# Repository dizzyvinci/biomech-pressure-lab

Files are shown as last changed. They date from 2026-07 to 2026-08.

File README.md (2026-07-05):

# Personal Biomechanics Lab

Measure how your foot is loaded — all day — and turn that into a **custom 3D-printed insole**
plus a plain-language read on **which tissues the load is stressing**. A ~$100 wearable and a
printer doing what a $5k+ gait lab does, at home.

> **Part of the biomech-lab family — the hardware / pressure side.** Its sibling **`biomech-lab`**
> covers markerless *motion* (webcam→OpenSim, DICOM/MRI bone geometry). **This** repo is the
> **build-your-own** side: a printed insole, an optional smart-insole sensor rig, and a DIY force
> plate + pressure mat you fabricate yourself.
>
> 🎤 One-pager pitch: [**PITCH.md**](PITCH.md) · 🩺 *A design & screening aid, not a medical device.*

---

## The flow — one loop, end to end

The whole system, end to end

Everything in the repo is a stage of one loop:

| # | Stage | Does | Tool |
|---|---|---|---|
| 1 | **Capture** | log foot pressure (8× FSR) + motion, all day | [`firmware/all_day_logger`](firmware/all_day_logger/all_day_logger.ino) |
| 2 | **Calibrate** | turn raw ADC into real **kPa** | [`calibrate.py`](analysis/calibrate.py) |
| 3 | **Analyze** | hot spot, pronation, cadence, balance/sway | [`interpret.py`](analysis/interpret.py) · [`balance.py`](analysis/balance.py) |
| 4 | **Dose** | the all-day **CPTS** load → which **nerves & fascia** it stresses | [`day_summary.py`](analysis/day_summary.py) → [`nerve_fascia.py`](analysis/nerve_fascia.py) |
| 5 | **Design** | a relief window + met pad + arch that follow the findings | [`build_insole.py`](hardware/build_insole.py) |
| 6 | **Print** | soft cushion + firm shell in one part | your **multi-material printer** |
| ↻ | **Track** | wear it, re-measure, watch the dose fall week over week | [`trend.py`](analysis/trend.py) |

**Two ways in, one destination:** Path 1 designs the insole *by feel* (no electronics); Path 2 adds
the sensor rig for *objective data*. **No hardware at all?** Every tool runs on the committed
sample with `--demo`.

---

## What you need to build it

### 🖨️ To PRINT the insole — a multi-material 3D printer  *(the one physical must-have)*
The insole is a **soft cushion + firm shell in a single print**, so it needs a printer that runs
two materials (e.g. a **Bambu Lab H2D** with the TPU High-Flow kit). This is the piece the whole
Path-1 workflow depends on.

| Part | Why |
|---|---|
| **Bambu Lab H2D** (or any multi-material printer) | prints soft cushion + firm shell in one insole |
| **TPU High-Flow kit** | nozzles tuned for flexible TPU |
| **Soft / foaming TPU** (e.g. VarioShore) | the squishy heel cushion that won't bottom out |
| **Firm TPU 95A** | the support shell |
| **PLA / PETG** | optional — enclosures, the DIY-lab frames, the FSR pucks |

Full list + links: [docs/parts_list.md](docs/parts_list.md).

### 🔬 To MEASURE (optional) — the sensor rig or the DIY lab
- **Smart-insole rig** (~$70–120): ESP32-S3 + 8× FSR + mux + IMU + microSD + LiPo. Gives a real
  hot-spot map and before/after proof. → **Path 2** below.
- **DIY lab instruments** (~$150): a **load-cell force plate** (vertical GRF ×BW) and a **Velostat
  pressure mat** (full-foot map) you print + wire. → [docs/build_lab.md](docs/build_lab.md).

---

## ▶️ Try it now — no hardware needed
[`sample/`](sample/README.md) runs the **entire pipeline on a synthetic day** (~5 s, every output
committed): calibrate → real kPa → hot spot → **an insole the software designs itself** → the
all-day dose → nerve/fascia read → a balance screen.

<p align="center">
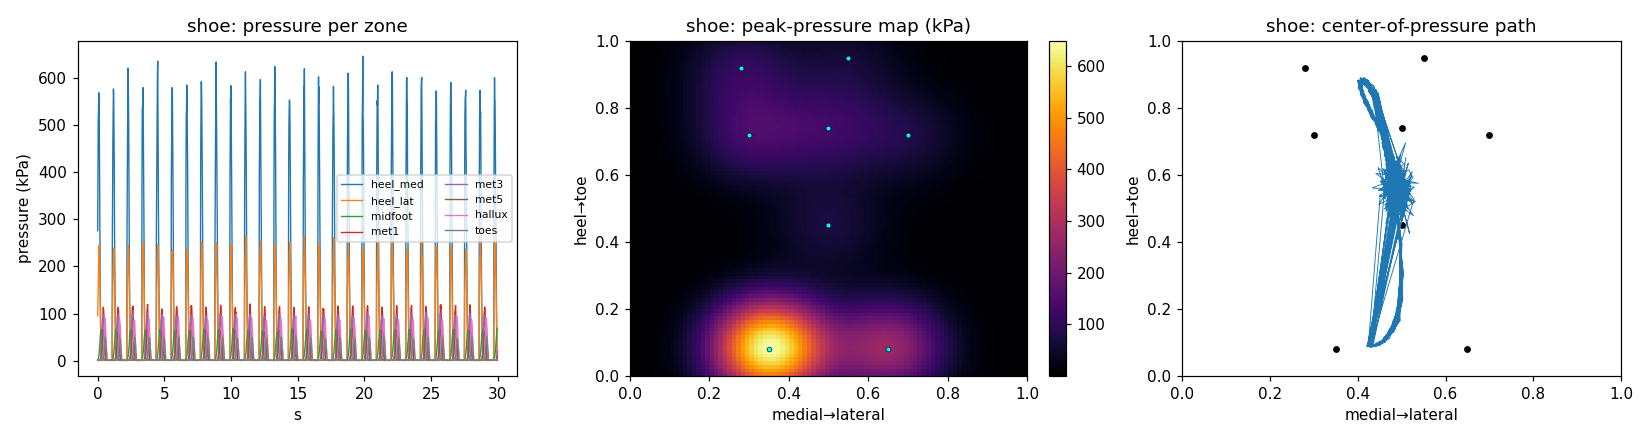
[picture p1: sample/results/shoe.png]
worked example: pressure per zone, peak-pressure heatmap, center-of-pressure path
  
</p>

**Worked result:** hot spot **heel_med (645 kPa, 40% of load)**, medial pronation, heel-dominant; the
shoe *adds* +13 pts vs barefoot → an **aggressive medial-heel relief insole with arch support**
([`hardware/relief_insole.stl`](hardware/relief_insole.stl)); the all-day dose flags **plantar fascia /
Baxter's / tibial** (tell-apart by time-of-day); balance **Romberg 3.6** (vision-reliant).

```bash
cd analysis
python make_sample_data.py --out ../sample                                      # fake a day
python calibrate.py ../sample/cal_points.csv --out ../sample/calibration.json --r-fixed 1000
python interpret.py "../sample/sample_day_*.csv" --calibration ../sample/calibration.json --out ../sample/results
python nerve_fascia.py --logs "../sample/sample_day_*.csv" ../sample/sample_seated_bounce.csv \
    --calibration ../sample/calibration.json --walk-hours 10 --bounce-hours 4 --out ../sample/results
cd ../hardware && python build_insole.py --spec ../sample/results/insole_spec.json --out .
```
Full walkthrough: [sample/README.md](sample/README.md) · both paths step-by-step: [docs/quickstart.md](docs/quickstart.md).

---

## 🖨️ Path 1 — printer-first (start here)
No electronics, no soldering. You already know where it hurts.
1. **Scan** your orthotic → STL (iPhone photogrammetry: Scaniverse/Polycam) — [docs/insole_print_spec.md](docs/insole_print_spec.md) §1.
2. **Mark** the sore spot on the scan.
3. **Design** the insole (soft heel cushion + firm shell + a **relief pocket** there) — or let
   [`build_insole.py`](hardware/build_insole.py) generate it, **fitted to your foot** ([how](docs/fit_to_your_foot.md)).
4. **Print** in TPU on the H2D (soft + firm in one part).
5. **Wear it**, nudge the window/density by feel, **reprint.** That's the loop — no measurement hardware.

---

## 🔬 Path 2 — the sensor rig (optional, advanced)
Add this only when you want to *measure* the hot spot instead of placing it by feel. The full
all-day, **barefoot-and-shoe** build is spec'd end-to-end in
[**docs/path2_tracking_build.md**](docs/path2_tracking_build.md) — electronics ride in an **ankle
pod** ([`hardware/ankle_pod.scad`](hardware/ankle_pod.scad)), not underfoot.

How the smart-insole rig fits together

<details>
<summary><b>Sensor-rig BOM, wiring, FSR map & data format</b></summary>

**BOM (~$70–120):** ESP32-S3 DevKitC-1 · 8× **FSR402** · **CD74HC4067** 16-ch mux · **BNO085** IMU ·
microSD SPI module · 8× 10 kΩ · LiPo 500 mAh + **TP4056** · EVA/wire/tape.
*(DIY FSR insoles validate to **r ≈ 0.87** vs pro systems — plenty for relative hot-spot mapping.)*
Each part explained: [docs/what-each-part-is-for.md](docs/what-each-part-is-for.md).

**Wiring (ESP32-S3):** mux SIG→GPIO1 (ADC1_CH0); mux S0–S3→GPIO2/3/4/5; IMU SDA/SCL→GPIO8/9;
SD CS/MOSI/SCK/MISO→GPIO10/11/12/13; button→GPIO14; LED→GPIO15. Each FSR:
`3V3 ── FSR ──●── 10kΩ ── GND`, node `●` → a mux channel.

**FSR → foot-zone map** (channel order in firmware/analysis):
```
        toes                  0 heel_med   4 met3
   hallux   met5              1 heel_lat   5 met5
 met1   met3                  2 midfoot    6 hallux
      midfoot                 3 met1       7 toes
 heel_med  heel_lat
```

**Data (CSV, ~50–100 Hz):** `t_ms,mode,phase,fsr0..fsr7,qw,qx,qy,qz,ax,ay,az,vbat`
(`phase` = walk/stand/bounce/other; short-press cycles it so a day segments for the dose model).
</details>

---

## 🧰 The toolbox — `analysis/`, by job
Every script runs standalone with `--demo`. Grouped by what you're asking:

| Job | Scripts |
|---|---|
| **Calibration & data** | [`calibrate.py`](analysis/calibrate.py) (fit ADC→kPa) · [`calib.py`](analysis/calib.py) (shared model) · [`make_sample_data.py`](analysis/make_sample_data.py) |
| **Pressure & insole** | [`interpret.py`](analysis/interpret.py) (findings + insole directives) · [`analyze_pressure.py`](analysis/analyze_pressure.py) (peak/impulse/CoP plots) · [`zone_load.py`](analysis/zone_load.py) (per-met vs cited norms) |
| **Balance & sway** | [`balance.py`](analysis/balance.py) (sway, Romberg) · [`balance_positions.py`](analysis/balance_positions.py) (mCTSIB, single-leg, LOS) · [`beam_balance.py`](analysis/beam_balance.py) (athlete/beam) · [`landing_lab.py`](analysis/landing_lab.py) |
| **All-day dose → tissue** | [`bounce.py`](analysis/bounce.py) (the at-rest forefoot dose) · [`day_summary.py`](analysis/day_summary.py) (day → peak/PTI/cycles) · [`nerve_fascia.py`](analysis/nerve_fascia.py) (CPTS → structures) · [`trend.py`](analysis/trend.py) (dose over weeks) |
| **DIY-lab instruments** | [`mat_heatmap.py`](analysis/mat_heatmap.py) (Velostat map) · firmware: [`force_plate`](firmware/force_plate/force_plate.ino) · [`pressure_mat`](firmware/pressure_mat/pressure_mat.ino) |
| **Integrations** | [`integrations/`](integrations/README.md): `video_force` · `apple_watch` · `gait_cue` · `walker` · `api_server` |

---

## 🗺️ Repository map
| Folder | What's in it |
|---|---|
| [`analysis/`](analysis/) | all the Python — the toolbox above |
| [`firmware/`](firmware/) | ESP32 sketches: `all_day_logger`, `smart_insole`, `fsr_calibrate`, `force_plate`, `pressure_mat` |
| [`hardware/`](hardware/README.md) | printable models (`.scad`+`.stl`): insole, ankle pod, sole, force plate, mat, FSR puck + [`build_insole.py`](hardware/build_insole.py) |
| [`refs/`](refs/README.md) | `plantar_norms.json` — the **cited** norms DB (pressures, thresholds, conditions, nerve/fascia structures) |
| [`sample/`](sample/README.md) | the reproducible worked example + committed outputs |
| [`docs/`](docs/README.md) | guides, specs, and the diagram source — **[docs index →](docs/README.md)** |
| [`integrations/`](integrations/README.md) | Apple Watch / cueing glasses / walker / REST API |

---

## 🖼️ Gallery
The system in pictures, grouped. (Diagrams are code-generated — [`docs/make_graphics.py`](docs/make_graphics.py).)

<details open>
<summary><b>Foundations & flow</b></summary>

System pipeline
Physical setup — electronics off the foot
Ordered vs printed BOM
A day of use
</details>

<details>
<summary><b>Pressure, insole & conditions</b></summary>

Plantar pressure atlas — real published kPa
Zone load vs the field
Condition-aware (toe-walking, equinus, heel pain)
Heel lifts & pressure-time integral
Kinetic chain + video→force
</details>

<details>
<summary><b>Balance & sport</b></summary>

Software modules — pressure + balance
Balance module detail — Romberg, fall risk
Balance across positions — mCTSIB, single-leg, LOS
Balance-assist ecosystem — Apple Watch, cueing glasses, walkers
Beam / athlete balance — the landing "stick"
Landing lab — one landing, three rubrics
</details>

<details>
<summary><b>The all-day dose → nerves & fascia</b></summary>

The hidden forefoot dose — leg-bounce
Nerve & fascia impact — CPTS → structures
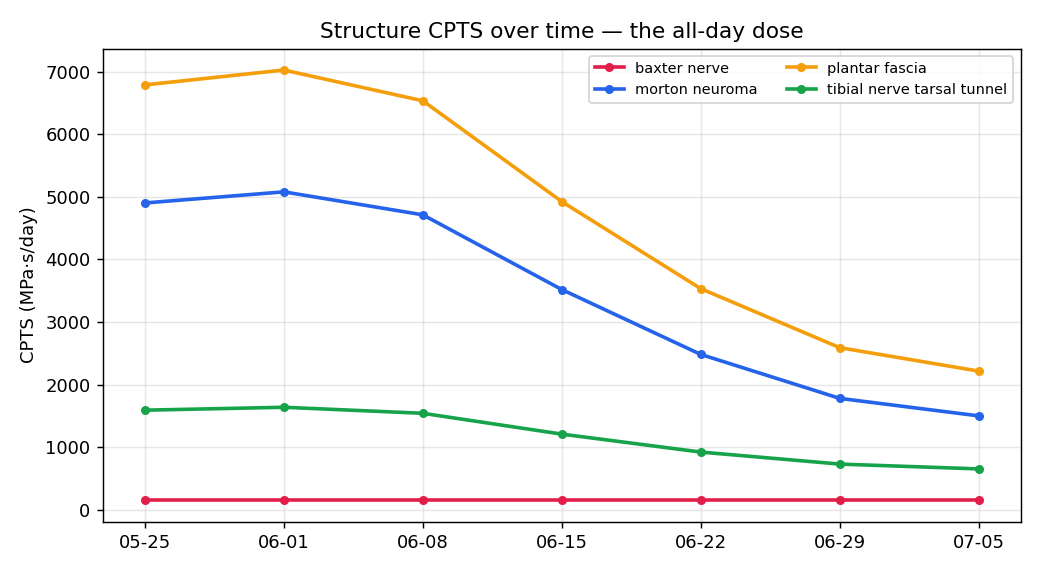
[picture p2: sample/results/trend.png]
CPTS trend over time

</details>

<details>
<summary><b>Build the DIY lab</b></summary>

Personal-lab scope — vs the papers' $10-30k gear
Maker hacks — reclaim the accuracy cheap sensors lose
</details>

---

## ⚠️ Safety & expectations
A **design & screening aid, not a medical device** — pair it with a clinician for pain. FSRs give
**relative, repeatable** pressure (calibrate for kPa; they drift — read trends). The nerve/fascia
read is **screening, not diagnosis** — those structures overlap, and confirming one needs an exam
+ imaging or a diagnostic block. You already have custom orthotics; treat this as tuning on top.

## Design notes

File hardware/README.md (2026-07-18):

# hardware — the printable 3D models

Parametric **OpenSCAD** source **plus pre-rendered STLs** — ready to slice today.

| Source | STL (ready to slice) | Preview | Print in | What |
|---|---|---|---|---|
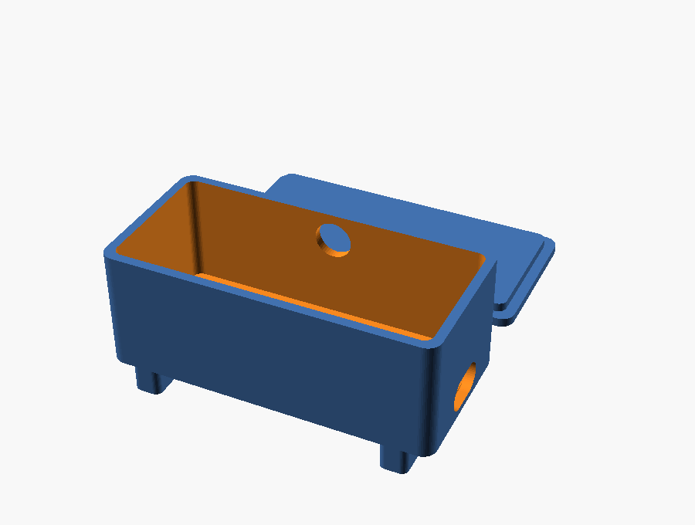
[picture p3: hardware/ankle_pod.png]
ankle pod
| [`ankle_pod.scad`](ankle_pod.scad) | [`ankle_pod.stl`](ankle_pod.stl) |  | PLA / PETG | Enclosure for ESP32-S3 + LiPo + microSD; USB-C + button + ribbon cutouts + strap slots |
| [`ankle_pod_enclosure.scad`](ankle_pod_enclosure.scad) | *(no STL yet — customize + export)* | — | PETG / PLA-CF | **STEMMA-QT revision** of the ankle pod — ESP32-C6 Feather + LiPo 2500 mAh + MPU-6050, snap lid. See [`../docs/BUILD_PLAN.md`](../docs/BUILD_PLAN.md) |
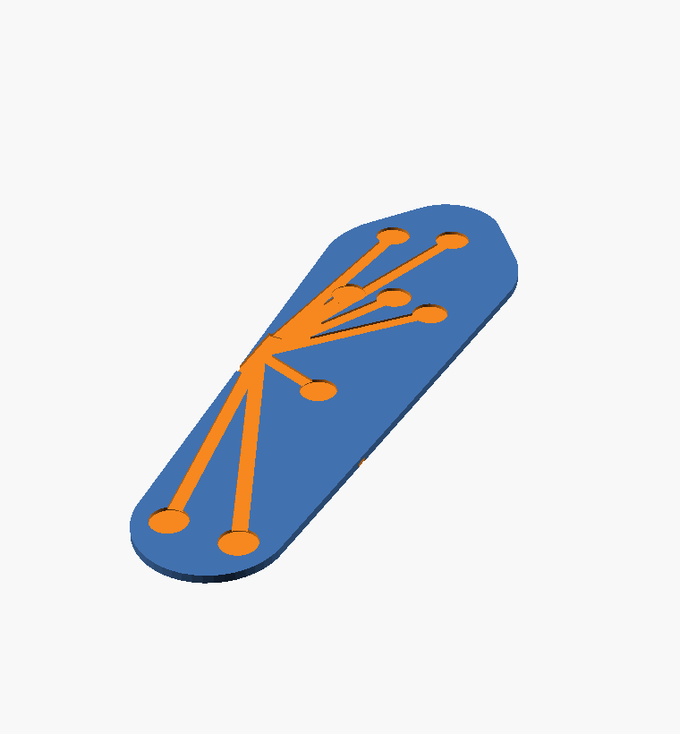
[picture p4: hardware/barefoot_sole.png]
barefoot sole
| [`barefoot_sole.scad`](barefoot_sole.scad) | [`barefoot_sole.stl`](barefoot_sole.stl) |  | **soft TPU 85A** | Thin footbed with 8 FSR pockets + wire channels + strap slots |
| [`insole_fsr_layout.scad`](insole_fsr_layout.scad) | *(no STL yet — customize + export)* | — | soft TPU (or PLA for a quick jig) | **6-zone FSR carrier/layout plate** for the STEMMA-QT rig — parametric off one `FOOT_LEN`. See [`../docs/insole_sensor_layout.md`](../docs/insole_sensor_layout.md) |
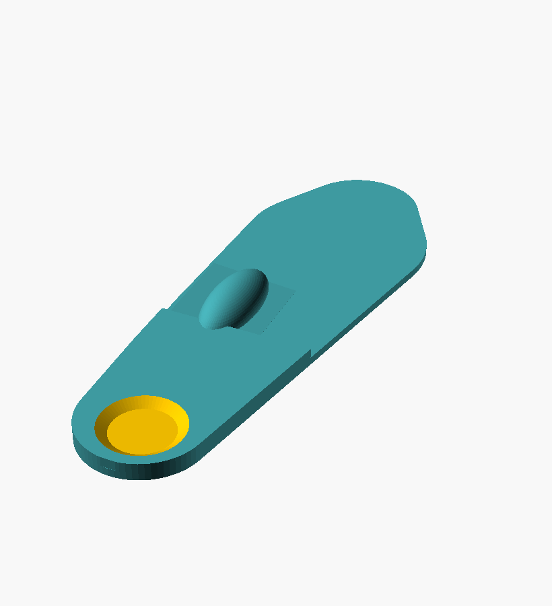
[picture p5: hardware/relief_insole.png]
insole
| [`build_insole.py`](build_insole.py) | [`relief_insole.stl`](relief_insole.stl) |  | soft + firm TPU | **The relief insole** — generated from `insole_spec.json`; fits to your foot (see below) |

## 🦶 Fit the relief insole to your foot
`build_insole.py` reads your analysis (`insole_spec.json`) and emits the insole with the
relief window / posting / cushion placed **from your data**. Three fit levels:
```bash
# generic footbed
python build_insole.py --spec ../sample/results/insole_spec.json
# fitted to your measurements (mm)
python build_insole.py --spec ... --length 262 --forefoot-width 99 --heel-width 64 --arch-height 14
# fitted to a scan of your existing orthotic (best)
python build_insole.py --spec ... --scan my_orthotic.stl --name fitted
```
Full how-to (measuring, scanning, mesh cleanup): [`../docs/fit_to_your_foot.md`](../docs/fit_to_your_foot.md).

## 🔬 Bigger builds — the DIY lab (close the equipment gaps)
Printable instruments that add what the insole can't — see [`../docs/build_lab.md`](../docs/build_lab.md)
and the scope in [`../docs/lab_scope.md`](../docs/lab_scope.md).

| File | STL | Print | What it builds |
|---|---|---|---|
| [`force_plate.scad`](force_plate.scad) | [`force_plate.stl`](force_plate.stl) | PETG, 100% infill | **Force plate** — 4× load-cell corner feet + top → **vertical GRF (×BW)**, ICC>0.94 (CoP via the 4-HX711 upgrade) |
| [`pressure_mat.scad`](pressure_mat.scad) | [`pressure_mat.stl`](pressure_mat.stl) | PLA/PETG | **Velostat pressure-mat frame** — electrode-alignment comb → a **full-foot pressure map** |
| [`fsr_puck.scad`](fsr_puck.scad) | [`fsr_puck.stl`](fsr_puck.stl) | **rigid** PLA/PETG | **FSR force-concentrator puck** — one per sensor; funnels load onto the FSR the same way every time (the #1 repeatability hack) |

Firmware: [`../firmware/force_plate/`](../firmware/force_plate/force_plate.ino) (1 HX711 → total force; 4-HX711 CoP upgrade in-sketch)
and [`../firmware/pressure_mat/`](../firmware/pressure_mat/pressure_mat.ino) (Velostat matrix scan).

**Dial in the accuracy:** [`../docs/maker_hacks.md`](../docs/maker_hacks.md) — the field-tested tricks
(anti-ghosting scan, median filtering, force-concentrator puck, bicubic interpolation) that recover
most of what the cheap sensors lose. The code-able ones are already in the firmware + `analysis/mat_heatmap.py`.

## Print now (STLs are committed)
The `.stl` files above are already rendered at the default parameters — **drop them straight into Bambu Studio and slice.** No OpenSCAD needed unless you want to customize.

## Customize + re-export (2 minutes)
1. Install **[OpenSCAD](https://openscad.org/downloads.html)** (free, Win/Mac/Linux).
2. Open a `.scad` file.
3. **Edit the parameters at the top** to your parts (measure your board / your foot).
4. Press **F6** (full render) → **File ▸ Export ▸ Export as STL**.
   *(CLI equivalent: `openscad -o ankle_pod.stl ankle_pod.scad`)*
5. Slice in **Bambu Studio** and print.

## Print settings (starting points)
| Part | Material | Notes |
|---|---|---|
| **Ankle pod** | PLA or PETG | 0.4 mm, 3 walls, 20% infill; PETG if it'll get warm/sweaty |
| **Barefoot sole** | **soft TPU 85A** | 0.4/0.6 mm (TPU High-Flow hotend), ~15% gyroid, 3 walls; glue stick helps release |
| **Final insole** | soft + firm TPU | see [`../docs/insole_print_spec.md`](../docs/insole_print_spec.md) — dual-material on the H2D |

## True-fit tip
For a shoe insole that matches your foot, don't use the generic `barefoot_sole` outline — **boolean the FSR-pocket pattern into your *scanned* orthotic/insole** (scan per [`../docs/insole_print_spec.md`](../docs/insole_print_spec.md)).

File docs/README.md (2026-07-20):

# Docs index

Guides and specs, grouped. (Start at the [project README](../README.md) for the big picture and
the end-to-end flow.) The `.svg` files here are **code-generated diagrams** — regenerate them with
[`make_graphics.py`](make_graphics.py); they're embedded in the READMEs, not read directly.

### Start here
| Doc | What |
|---|---|
| [quickstart.md](quickstart.md) | Both paths, step by step |
| [prototype_status.md](prototype_status.md) | "Is it ready to build / pitch?" + ordered-vs-printed BOM |
| [prior_art.md](prior_art.md) | How this compares to existing systems |
| [analysis_and_implications.md](analysis_and_implications.md) | What the metrics mean and why |

### Path 1 — the printed insole
| Doc | What |
|---|---|
| [insole_print_spec.md](insole_print_spec.md) | ⭐ The insole design + print settings (relief window, density zones) |
| [fit_to_your_foot.md](fit_to_your_foot.md) | Fit the insole by measurements or a scan of your orthotic |
| [parts_list.md](parts_list.md) | Every part + buy links (printer path + optional rig) |
| [what-each-part-is-for.md](what-each-part-is-for.md) | Plain-English part purposes |

### Path 2 — the sensor rig
| Doc | What |
|---|---|
| [path2_tracking_build.md](path2_tracking_build.md) | The all-day barefoot-and-shoe tracking build, end to end |
| [calibration.md](calibration.md) | Turning raw FSR ADC into real kPa |
| [opencap_setup.md](opencap_setup.md) | Optional markerless motion capture |
| [insole_sensor_layout.md](insole_sensor_layout.md) | FSR zone coordinates for the 6-zone STEMMA-QT (ESP32-C6 Feather) rig |
| [BUILD_PLAN.md](BUILD_PLAN.md) | ⭐ STEMMA-QT ankle-pod build: print list, wiring, assembly order, calibration |
| [WIRING.md](WIRING.md) | Pin-by-pin solder guide for the 6 FSR dividers — which pad connects where |

### The analysis — what it measures
| Doc | What |
|---|---|
| [zone_load.md](zone_load.md) | Per-metatarsal over/under-use vs cited sports-med norms |
| [conditions.md](conditions.md) | Condition-aware: toe-walking, equinus, heel pain (+ the bounce dose) |
| [nerve_fascia.md](nerve_fascia.md) | The all-day dose (CPTS) → nerves & fascia + the trend/insole hooks |
| [balance.md](balance.md) · [balance_positions.md](balance_positions.md) · [balance_assist.md](balance_assist.md) | Posturography, mCTSIB, and the assist ecosystem |
| [beam_balance.md](beam_balance.md) · [landing_lab.md](landing_lab.md) | Athlete balance + discipline-scored landings |
| [video_force.md](video_force.md) | Estimating force from video when there's no sensor |

### Build the DIY lab (close the equipment gap)
| Doc | What |
|---|---|
| [lab_scope.md](lab_scope.md) | What the cited papers' gear is vs what we DIY, and the honest gaps |
| [build_lab.md](build_lab.md) | Build guide: load-cell force plate + Velostat pressure mat |
| [maker_hacks.md](maker_hacks.md) | Field-tested tricks to reclaim the accuracy cheap sensors lose |

### Reference data
| [../refs/README.md](../refs/README.md) | The cited norms DB — pressures, thresholds, conditions, nerve/fascia structures |

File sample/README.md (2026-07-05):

# Worked example — the whole pipeline, no hardware

This folder is a **self-contained demo**: a *synthetic* day of data run through the
entire pipeline, so you can see exactly what the system produces before you build
anything. Everything here is regenerated by the scripts (all values below are the
committed run).

> ⚠️ **Synthetic data**, generated by [`../analysis/make_sample_data.py`](../analysis/make_sample_data.py)
> from a physically-consistent FSR model — **not** a real measurement. It's seeded to
> tell a realistic story (a medial-heel hot spot + a vision-reliant balance pattern).

## Reproduce it (≈5 s)
```bash
cd analysis
python make_sample_data.py --out ../sample                                   # 1. fake a day of data
python calibrate.py ../sample/cal_points.csv --out ../sample/calibration.json --r-fixed 1000   # 2. fit ADC→kPa
python interpret.py "../sample/sample_day_*.csv" --calibration ../sample/calibration.json --out ../sample/results   # 3. pressure → directives
python balance.py ../sample/sample_balance.csv --calibration ../sample/calibration.json --out ../sample/results     # 4. balance
python analyze_pressure.py "../sample/sample_day_*.csv" --calibration ../sample/calibration.json --out ../sample/results  # 5. plots
python day_summary.py "../sample/sample_day_*.csv" ../sample/sample_seated_bounce.csv --calibration ../sample/calibration.json --walk-hours 10 --bounce-hours 4 --out ../sample/results  # 5b. all-day dose (peak/PTI/cycles)
python nerve_fascia.py --day ../sample/results/day.json --out ../sample/results   # 5c. all-day dose → nerve/fascia impact
python trend.py --demo --out ../sample/results                                    # 5d. (demo) CPTS per structure over weeks
cd ../hardware && python build_insole.py --spec ../sample/results/insole_spec.json --out .     # 6. data → printable insole (follows the structure target)
```
Step 6's insole now **follows the structure read** — the sample's medial-heel/pronation pattern
auto-enables **arch support** ([results/report_trend.md](results/report_trend.md) shows the trend view;
a Morton's forefoot pattern would instead add a **metatarsal pad**).
Steps 5b–5c turn a **real day** (walking `sample_day_*.csv` + at-rest bouncing `sample_seated_bounce.csv`)
into the **CPTS all-day dose** and the **nerve/fascia** read ([results/report_nerve_fascia.md](results/report_nerve_fascia.md),
[results/day.json](results/day.json)). One-command equivalent: `nerve_fascia.py --logs "…csv" --calibration … --walk-hours 10 --bounce-hours 4`.

## 1. Calibration (ADC → real kPa)
`calibrate.py` fits each FSR's power law `F = a·G^b` from known weights → **R² = 1.00**
on all 8 channels (recovers a≈2000, b≈0.75). Every number below is **real kPa**, not
a relative reading.

## 2. Pressure — foot pain / insole  ([results/report.md](results/report.md))
**Walking, shoe:**

shoe pressure

- Hot spot at **heel_med — 40% of total load**, peak **645 kPa** (barefoot 401 kPa).
- **Concentrated** at heel_med (>1.6× the next zone) → offload aggressively.
- **Medial 56% vs lateral 25%** → pronation tendency (medial posting).
- **Heel-dominant (59%)** + a **hard heel strike** → soft heel cushion.
- **Barefoot vs shoe:** the shoe *raises* heel_med load by **+13 pts** — footwear is
  adding to the hot spot; the printed insole should undo that.

**→ Design directives** (`results/insole_spec.json`):
`relief window @ heel_med (aggressive) · posting=medial · cushion=heel · soft heel`

## 3. Balance — stability / fall risk  ([results/report_balance.md](results/report_balance.md))
Quiet standing, eyes-open then eyes-closed:

| condition | sway area | velocity | flags |
|---|---|---|---|
| eyes_open | **211 mm²** | 31 mm/s | — |
| eyes_closed | **770 mm²** | 36 mm/s | large sway area, high velocity |

**Romberg quotient = 3.6** (eyes-closed / eyes-open). **>2 → strong reliance on vision**
(a proprioceptive/vestibular pattern worth a fall-risk screen).

## 4. The insole it designed  ([../hardware/relief_insole.scad](../hardware/relief_insole.scad))
`build_insole.py` reads the directives above and emits a print-ready model with the
relief pocket, medial post, and heel cushion **placed from the data** — no hand-editing:

generated insole

*Aggressive relief pocket at the medial heel (orange recess) · raised heel cushion ·
medial post through the arch.* Drop [`../hardware/relief_insole.stl`](../hardware/relief_insole.stl)
into Bambu Studio and print (soft TPU 85A heel/relief + firm TPU 95A shell).

---
**This is the pitch in one folder:** a day of data → calibrated kPa → findings →
a printable, custom insole, plus a balance/fall-risk screen — all from one ~$100 rig.

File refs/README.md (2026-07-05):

# refs — cited plantar-load reference database

[`plantar_norms.json`](plantar_norms.json) is the **norms** the analysis compares an
athlete against: per foot **zone** (down to the 2nd metatarsal), per **sport/movement**,
the expected **load distribution** and **peak force** — from published sports-medicine
research where possible.

## Why a database (not just estimates)
A rubric is only as good as its reference. "Your met2 is at 21% of load" means nothing
until you know the field's norm is 16% — *then* it's a 1.3× overload and an injury flag.
So we keep the norms in one cited, versioned file that gets **more rigid as sources are
added**. `analysis/zone_load.py` reads it.

## Honesty: every value carries a confidence flag
- **`published`** — the value/range is stated in the cited paper (e.g. gymnastics
  landing **7.1–15.8× BW**).
- **`published_order`** — the *ranking* of zones is from a paper (e.g. running: central
  met heads > 1st met > heel > hallux > lateral); magnitudes are filled to match.
- **`estimated`** — biomechanically reasonable, **no direct source yet** (a TODO to
  replace with data).

"Estimation fine, exact better": the peak-force ranges are mostly `published`; several
per-zone magnitude splits are `published_order` or `estimated` and clearly marked.
**Contributions = add a paper + tighten a distribution + flip a flag to `published`.**

## What's in it (v0.3)

plantar pressure atlas

**Real per-zone peak pressures (kPa)** now populate the bottom-of-foot profiles:

| Activity | Published peak pressures (kPa) | Source |
|---|---|---|
| Barefoot **walking** | hallux **280** · heel **264** · met1 **248** · met2 **246** · met3 **225** | [PMC2902454](https://www.ncbi.nlm.nih.gov/pmc/articles/PMC2902454/) |
| Quiet **standing** | heel **139** vs forefoot **53** (heel 60% / midfoot 8% / forefoot 28% of load) | [Cavanagh](https://pubmed.ncbi.nlm.nih.gov/3583160/) |
| **Running** | forefoot **313** · total **364** · rearfoot mid/hind ~**190** | [PMC5112690](https://pmc.ncbi.nlm.nih.gov/articles/PMC5112690/) |
| **Basketball landing** | hallux **794** · forefoot **403** (central-forefoot 50% / hallux 25%) | [LER](https://lermagazine.com/special-section/defensive-game-planning/soccer-basketball-players-demonstrate-differences-in-plantar-pressure-patterns) |

Plus **`clinical_thresholds`** — 200 kPa in-shoe / 450 & 750 kPa barefoot ulcer-risk
([PMC10882031](https://pmc.ncbi.nlm.nih.gov/articles/PMC10882031/)) — with the explicit
note that these are **neuropathic-tissue** limits, **not** athletic caps (healthy
athletes routinely exceed them transiently).

Profiles (12): **`standing`**, **`walking`** (baselines), running (rear/forefoot),
gymnastics / figure-skating / **basketball** / jump landings, ballet (relevé/pointe),
soccer (sprint/cut). Each: `dist_pct`, `peak_pressure_kPa` (where sourced),
`peak_force_BW`, `watch_zones`, `injury` + `chain_injury`, sources. Plus:
- **`zone_anatomy`** — each zone's **anatomical position** (`pos_mm` on a 255 mm foot).
- **`chain_rules`** — foot **signatures → kinetic-chain injuries** (hamstring, ACL, shin).
- **Condition profiles** (v0.4) — `plantar_fasciitis`, `toe_walking`, `equinus`: a person's
  **adaptive/altered baseline**, so `zone_load.py --condition` doesn't false-flag it (a
  toe-walker's low heel is the norm) and instead surfaces the condition's real risks. See
  [../docs/conditions.md](../docs/conditions.md). Cited: ITW forefoot 61.7% ([PubMed 31946390](https://pubmed.ncbi.nlm.nih.gov/31946390/)),
  equinus forefoot 677.8 kPa ([PMC9338503](https://www.ncbi.nlm.nih.gov/pmc/articles/PMC9338503/)).

**v0.5** adds a **`metrics`** section (peak vs **pressure-time integral** — the cumulative-dose
injury predictor; met2 PTI ~38.4 kPa·s, [PMC11336220](https://www.ncbi.nlm.nih.gov/pmc/articles/PMC11336220/)),
a **`footwear_effects`** section (heel lifts offload the heel but raise forefoot pressure + PTI
→ design rule: offload heel **and** cushion forefoot, [PubMed 24440428](https://pubmed.ncbi.nlm.nih.gov/24440428/)),
and cutting flipped to published (peak @ met2, 1st-met shear 312–463 kPa, [J Biomech 2014](https://www.sciencedirect.com/science/article/abs/pii/S0021929014005491)).

heel lifts & PTI

**v0.6** adds a **`structures`** block — the **nerves & fascia** that specific loading patterns
overload (plantar fascia, Baxter's nerve, Morton's/interdigital nerve, posterior tibial/tarsal
tunnel), each with its zones, loading mode, differentiating clue, and citation — plus two metrics:
**CPTS** (cumulative plantar tissue stress = PTI × cycles/day, the all-day dose, [PMID 29477099](https://pubmed.ncbi.nlm.nih.gov/29477099/))
and the **pressure gradient** (subsurface shear near nerves, [PMC2387244](https://pmc.ncbi.nlm.nih.gov/articles/PMC2387244/)).
Consumed by [`analysis/nerve_fascia.py`](../analysis/nerve_fascia.py) → [nerve_fascia.md](../docs/nerve_fascia.md).
Associations are published; the zone-weights are `estimated`. Screening, not diagnosis.

nerve & fascia

Key sourced facts:
| | Finding | Source |
|---|---|---|
| Gymnastics | landing **7.1–15.8× BW** | [Front. Sports Act. Living 2025](https://pmc.ncbi.nlm.nih.gov/articles/PMC12179790/) |
| Figure skating | single-leg landing **~5× BW** (to ~8×) | [ACSM](https://acsm.org/the-science-of-figure-skating-jumps/) |
| Running | central met heads bear most; forefoot **281–313 kPa** | [PMC5112690](https://pmc.ncbi.nlm.nih.gov/articles/PMC5112690/) |
| Ballet | 1st-MTP pain → **less hallux, more met-head** load | [Children 2022](https://pmc.ncbi.nlm.nih.gov/articles/PMC9406650/) |
| Injury | **2nd met** = #1 stress-fracture site ("dancer's fracture") | [Physiopedia](https://www.physio-pedia.com/Metatarsal_Stress_Fractures_in_the_Athletic_Population) |

## Roadmap (more rigid)
- Replace `estimated` distributions with per-zone baropodometry from papers/our own captures.
- Add profiles: sprinting, jump-landing (volleyball/basketball, ACL), soccer cut, martial-arts kick, walking-gait clinical norms.
- **Video → force** estimation as a connector: 2D-pose → GRF is now feasible
  ([pose-estimation GRF, PMC11057390](https://www.ncbi.nlm.nih.gov/pmc/articles/PMC11057390/));
  it *estimates* the peak force, then this DB gives the *published* range to check it against.
- Our own captures (calibrated insole) feed back in — the DB tightens as we scale.

Not medical advice — a training/screening reference. Values summarize published research;
verify against primary sources for clinical use.

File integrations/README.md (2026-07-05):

# integrations — the balance-assist ecosystem

The insole senses; these turn it into a closed loop with the devices people already
use. Three layers:

```
 SENSE                     DECIDE                        ASSIST
 ─────                     ──────                        ──────
 insole (FSR + IMU) ─┐
 Apple Watch (gait) ─┼──►  balance state · fall-risk ──► Parkinson's cue glasses (lines/metronome)
 smart walker (load)─┘     freezing-of-gait (FOG)        smart walker (adaptive brake + alert)
                                                          haptic buzz (pod / watch)
```

| Module | Direction | What it does | Verified with |
|---|---|---|---|
| [`gait_cue.py`](gait_cue.py) | insole → **glasses** | Detects **freezing of gait** (Freeze Index) → emits a **cue-event stream** (visual floor-lines, metronome, haptic) that Parkinson's cueing glasses / laser-shoes act on | `--demo` (2 freezes → 10 cue events) |
| [`apple_watch.py`](apple_watch.py) | **Watch** → insole | Reads an **Apple Health export** (Walking Steadiness, asymmetry, double-support, speed) and cross-references the insole findings for a **two-source fall-risk view** | `sample/apple_health_export_sample.xml` |
| [`walker.py`](walker.py) | walker ↔ insole → **walker** | Fuses **handle load + foot load** → % weight through the walker (rehab trend), lean, and a **grab detector** that fires **brake + alert** on a near-fall | `--demo` (3 grabs → brake commands) |
| [`video_force.py`](video_force.py) | **video** → force | Estimates peak **vGRF from CoM trajectory** (pose) — check vs the cited DB range; flags **L/R asymmetry** (ACL precursor). Fills in when there's no insole | `--demo` (6.8× BW; 20% asym) |

## What's built vs what needs the device
These modules implement the **algorithms + the data contracts**. The last hop to a
physical device is a thin transport the target hardware defines:

- **Cue glasses / laser-shoes** — consume `cue_events.json` events over **BLE** (or the
  ESP32 drives a GPIO to a laser / an audio DAC for the metronome). Many Parkinson's
  cueing products already take a simple on/off + tempo signal.
- **Apple Watch** — the export adapter works today; **live** sync needs a small
  companion **iOS app** using HealthKit (`HKQuantityTypeIdentifierAppleWalkingSteadiness`
  et al.) to stream the same fields. The Watch IMU can also be an extra trunk channel.
- **Smart walker** — consumes `walker_feedback.json` `brake`/`alert` commands over
  **BLE/serial**; robotic rollators with electronic brakes expose exactly this.

## Event & telemetry schemas
**Cue events** (`gait_cue.py` → glasses/laser/metronome/haptic):
```json
{ "t": 13.0, "channel": "visual_lines|metronome|haptic",
  "action": "on|off|start|stop|buzz", "params": { "spacing_cm": 40, "bpm": 110 } }
```
**Walker telemetry in** (CSV): `t_ms, handle_L_N, handle_R_N, speed_mps[, foot_load_N]`
**Walker feedback out** (`walker.py` → robotic walker):
```json
{ "t": 10.0, "channel": "brake|alert", "action": "engage|release|notify",
  "params": { "level": "high", "msg": "steady — weight onto your feet" } }
```

## API — connect any app (two directions)
The engine is exposed as an HTTP API so *anything* can connect — a coaching app, a
clinician dashboard, a phone app driving the cue glasses, a caregiver alert.

**Inbound** — [`api_server.py`](api_server.py) (dependency-free stdlib):
```
GET  /health                              liveness + tool list
GET  /openapi.json                        machine-readable spec (point any client at it)
POST /analyze/{tool}   body = CSV log  -> analysis JSON
GET  /events/{tool}?demo=1             -> cue / feedback event stream
       tool ∈ pressure balance balance_positions beam landing fog walker
```
```bash
python api_server.py --port 8787
curl -s -X POST --data-binary @session.csv "http://localhost:8787/analyze/landing?discipline=dance"
curl -s "http://localhost:8787/events/fog?demo=1"
```

**Outbound** — [`connectors.py`](connectors.py): push events to other services' webhooks.
Register a URL per event-type in a `connectors.json` (see
[`connectors.sample.json`](connectors.sample.json)) — add a service by adding a URL:
```json
{ "events": { "fall_alert": ["https://caregiver.example/webhook"],
              "landing_score": ["https://coach-app.example/hooks/landing"],
              "cue": ["https://glasses.example/cue"] } }
```
```bash
python connectors.py --demo                                   # dry-run the payloads
python connectors.py --config connectors.json --emit fall_alert --data '{"severity":"high"}' --live
```
One event bus in, one event bus out — that's how "connect to other things" scales:
each new partner is a URL, not a rewrite. Production adds auth + a real ASGI server.

---
Everything is a screening / assistive / performance prototype — **not a medical device**.
Pair with a clinician (neurology / PT / audiology) or coach.

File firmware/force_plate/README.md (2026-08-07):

# `force_plate` — pressure/force firmware

**Repo:** `biomech-pressure-lab` · **Written:** 2026-08-07 · **Status: COMPILES CLEAN, UNTESTED ON HARDWARE.**

Nothing in this folder has been flashed. No serial port has been opened. No HX711, load cell or FSR
has ever been connected to it. Every number it prints is unverified until §6 has been run.

---

## 0. Read this before you pick anything up

Two things are true at once and both matter:

* The pressure subsystem is the only one in this tree with **printed parts physically on the desk**
  (`BIO-FORCE-PLATE`, `BIO-FSR-PUCK-01`, PETG, job `1148490506`, 2026-08-07).
* **It is not a force plate yet, and the blocker was never firmware.**

`hardware/BENCH_NEXT_STEPS.md` §0 settled the geometry: `force_plate.stl` is **one `foot()`**
(19.0 × 26.0 × 21.0 mm), not a plate. The rig wants 4 feet, 4 `top_boss()` and a top. You have
**1 / 0 / 0**, and `top_boss()` / `top_plate()` are still commented out in `force_plate.scad`, so no
STL exists for them. The one foot also printed in **plain PETG at ≤52 % effective density** against a
`PRINT_CARD.md:40` spec of PA-CF/PETG-CF at 100 % infill.

**So: nobody stands on this.** That is enforced in code, not asked for — `MAX_BENCH_N = 250 N`
latches an overload fault and stops the session. T1DM means reduced protective sensation: the
operator may not feel a corner bracket digging in or a rig beginning to fail, so the ceiling lives
where it does not depend on being felt.

**What you *can* do today, with zero purchases:** bench the HX711 and the FSR puck by hand and by
bench mass, calibrate them, and prove the whole acquisition/logging chain end to end. That is §6.

---

## 1. What was fixed, and the library question

The previous revision of `force_plate.ino` **did not compile**: `fatal error: HX711.h: No such file
or directory`. `FIRMWARE_SCOPE.md` flagged that missing library as handoff **H5** on 2026-08-05 and
it was never actioned — `arduino-cli lib list` still returns the same five libraries it returned
then (BusIO, GFX, MPU6050, SSD1306, Unified Sensor).

**This firmware does not wait on that handoff.** `hx711_lite.h` is a ~130-line inline driver, so the
sketch has **zero external dependencies** and builds on this machine as it stands. That is not just
convenience — the stock library's `wait_ready()` blocks forever on an absent or miswired amp, and a
silent hang is indistinguishable from "no load applied". Every read here takes a timeout.

*(Installing the missing libraries is still worth doing for the other repos' sketches. It is not
needed for anything in this folder, and I did not run it — installs belong to you.)*

Five other real defects fixed, listed with reasons in the header of `force_plate.ino`: a strapping
pin used for HX711 DOUT (**B2**), a 4-channel pin map that used **GPIO6/GPIO7 — bonded to the
WROOM-32's internal SPI flash, so touching them crashes the chip** (**B3**), a hard-coded
`BODY_N = 700.0` dividing every output by an unsourced body weight (**B4**, the same defect
`analysis/balance.py` already refuses for `FOOT_L_MM`), no read timeouts (**B5**), and calibration
stored in a source constant so it died on every reflash (**B6**).

---

## 2. The HX711 count decides everything — and it is ONE

> `ergonomics/carts/INVENTORY.md:259` — *"4× 50 kg load cells + HX711 amp | 8.49"*
> `FIRMWARE_SCOPE.md` parts ledger — *"4× 50 kg load cell + HX711 | **1 set**"*

**One amplifier.** That is the whole answer to the total-force-vs-centre-of-pressure question:

| Mode | Amps | Wiring | Output | Buildable now? |
|---|--:|---|---|---|
| `MODE_TOTAL` **(default)** | 1 | 4 half-bridge cells → **one** full Wheatstone bridge (bathroom-scale topology) | total vertical force only | ✅ **yes** |
| `MODE_AP` | 1 | 4 cells → **two** full bridges → HX711 ch A + ch B | total **+ 1-D anterior/posterior CoP** | ✅ yes, but rewire + untested |
| `MODE_COP4` | 4 | 4 full-bridge cells, one amp each, shared clock | full **2-D CoP** | ❌ needs 3 more HX711 → §8 |

`MODE_AP` is the interesting one and it costs nothing: instead of summing all four half-bridge cells
into a single bridge, pair them front/front and rear/rear into **two** bridges and read them on the
HX711's two channels. **Caveat that must not be glossed:** channel B's gain is **fixed at 32** where
channel A is 128, so the rear line is roughly **4× coarser**. It is a real 1-D CoP, not a substitute
for a 4-cell rig. Marked untested because it is.

All three modes compile (§7). Select with `-DACQ_MODE=0|1|2`.

---

## 3. Wiring

### 3.1 Load cells → HX711

Each 50 kg cell is a **half bridge, 3 wires**: red = centre tap, black and white = bridge ends.
Combining four into one full bridge is the standard SparkFun load-cell-combinator pattern — opposite
corners take tension vs compression, so they sum.

| HX711 pin | Goes to | Conductor |
|---|---|---|
| `E+` | red of cells 1 & 3 | cell pigtail as supplied |
| `E−` | red of cells 2 & 4 | cell pigtail as supplied |
| `A+` | white of 1 & 2, black of 3 & 4 | cell pigtail as supplied |
| `A−` | black of 1 & 2, white of 3 & 4 | cell pigtail as supplied |
| `B+` / `B−` | *unused in `MODE_TOTAL`* — leave open | — |

For **`MODE_AP`**: cells 1+2 form one bridge into `A+/A−`, cells 3+4 form the second into `B+/B−`.

### 3.2 HX711 + SD + FSR → ESP32-WROOM-32 DevKitC

**Board:** `esp32:esp32:esp32` (Elegoo ESP-32 3-pack). The ESP32-C6 Feather is *not* used here —
`SENSING_DEVICES_PLAN.md:587` assigns the Feather to the worn insole/ankle pod.

| Signal | GPIO | Direction | Conductor | Why this pin |
|---|--:|---|---|---|
| HX711 `PD_SCK` | **27** | out | 28 AWG silicone | safe GPIO, not strapping, not flash |
| HX711 #0 `DOUT` | **34** | in | 28 AWG silicone | **input-only pin — ideal**, and DOUT is push-pull so it needs no pull-up (GPIO34-39 have none) |
| HX711 #1–3 `DOUT` | 35 / 36 / 39 | in | 28 AWG silicone | `MODE_COP4` only, amps not owned |
| HX711 `VCC`, `GND` | 3V3, GND | — | 28 AWG silicone | 3.3 V rail; do **not** feed 5 V into a 3.3 V logic pin |
| FSR puck A | **32** | in | 28 AWG bench / **22 AWG in-shoe** | ADC1_CH4 |
| FSR puck B | **33** | in | 28 AWG bench / **22 AWG in-shoe** | ADC1_CH5 |
| SD `CS` | **5** | out | 28 AWG silicone | VSPI CS; it *is* a strapping pin but CS idles HIGH, which is the level the strap wants |
| SD `SCK` / `MOSI` / `MISO` | 18 / 23 / 19 | — | 28 AWG silicone | VSPI defaults |
| Status LED | 2 | out | onboard | ~3 mA. **The only output pin in this firmware.** |

**Pins deliberately avoided:** `GPIO6–11` are bonded to the WROOM-32's internal SPI flash — using
them crashes the chip, and the previous revision used two of them. `GPIO0/12/15` are strapping pins.

### 3.3 Conductor gauge — this is a medical constraint, not a preference

* **28 AWG silicone stranded (Adafruit 3890, 10-way ribbon, 1 m) is OWNED** and is correct for every
  run in the table above. It is also the *only* correct choice for anything on the head or crossing a
  hypermobile joint: 22 AWG there adds mass and bending stiffness against a structure that cannot
  resist it.
* **⚠️ The owned metre of 3890 is committed to the rib-follower→mux loom.** Do not consume it on this
  bench rig without deciding that trade explicitly.
* **22 AWG silicone stranded is the right spec for the in-shoe FSR run** (`docs/WIRING.md:199` — it is
  a longer, more abused, non-worn-on-head path) **and is NOT ON HAND** (`INVENTORY.md:156`). It is
  already **in the active cart, not ordered** (TUOFENG `B07G2JWYDW`, $15.69, carted 2026-08-07).
  `INVENTORY.md:577` names its scope precisely: *"unblocks the bed mat + force plate only, and is the
  wrong conductor for HUD temples / exo §4.1 / ribs Track C."* This subsystem is one of the two things
  it is genuinely for. → §8.
* Everything on this bench is currently **solderless-or-nothing**: breadboards and jumpers are
  explicitly not owned (`INVENTORY.md:162`). Perfboard *is* owned but requires solder *and* wire.

### 3.4 FSR divider

`3V3 ──[ FSR ]── node ──[ 10 kΩ ]── GND`, node → ADC pin. The 25× 10 kΩ pack (Adafruit 2784) arrived
with order #3716034 (delivered ~07-28, packing slip photographed IMG_0765). The printed
`fsr_puck` is the load-spreading cap that sits on the pad.

---

## 4. Calibration — a procedure you can actually run

Commands over serial at **115200**. Type `HELP` for the full list.

1. **Power up and leave it alone for two minutes.** HX711 + strain gauges drift while warming.
   Taring cold and then measuring produces a slow ramp that reads exactly like material creep.
2. `ID` — confirm mode and pin map.
3. `RAW` — you should see `ch0=` with counts moving when you press the rig. `TIMEOUT` means the amp
   is not answering: check `VCC`, `E+`/`E−`, `DOUT`, `CLK`.
4. `ZERO` — 60-second drift check with nothing touching the rig. It prints the spread in newtons.
   **A spread above ~2 N means it is still warming up — wait and repeat.** Do not skip this.
5. `TARE` — zeroes every channel.
6. Put a **known mass** on the rig, then `CAL 0 <kg>`.
   * **The mass has to be big enough.** A 200 kg-capacity rig reading a 200 g reference sits in the
     noise, and a scale factor fitted there is worthless. The firmware **refuses** any calibration
     where the reading moved less than 1000 counts and tells you why.
   * **Free reference that works:** a sealed **1 US gallon jug of water = 3.785 L ≈ 3.78 kg** at 20 °C.
     Water's density is the reference — you do not need to weigh it.
   * The owned 0.01 g pocket scale is excellent for weighing an FSR-scale reference (grams) and
     useless for a load-cell-scale one (kilograms). Both statements are true; use the right one for
     the right sensor.
   * A proper set of masses or a hanging scale is the real fix → §8.
7. `SAVE` — writes offsets and scale factors to NVS so they survive a reflash. (**B6**.)
8. Optional: `BW <kg>` to enable the `bw_ratio` column, and `GEOM <ap_mm> <ml_mm>` for CoP geometry.
   **If you skip `BW`, `bw_ratio` stays blank** — the firmware will not divide your data by a body
   weight nobody sourced.

**FSR calibration** is a different curve (power-law, not linear): use `firmware/fsr_calibrate`, log
`sensor,force_N,adc` rows into `cal_points.csv`, and fit with `python analysis/calibrate.py`.

---

## 5. Output format

### 5.1 Conditions are coordinates — and `START` enforces it

`START` is **refused** until all five condition fields are set:

```
COND posture=stand_2ft load=mass_only footwear=barefoot side=both surface=hard note=warmup_2min
START
```

`posture` · `load` · `footwear` · `side` · `surface` (+ optional `note`). Every row carries a
`cond_id`; changing any field increments it and rolls to a new SD file, so **no row can ever be
orphaned from the conditions it was taken under.** For bring-up without a condition there is `RAW`,
which is prefixed `#RAW`, is never written to SD, and is not CSV.

### 5.2 Timestamps — and the honest gap

There is **no RTC anywhere in this inventory**. Wall-clock time can therefore only come from the host:

```
TIME 1754582400        # unix seconds; sets the clock via settimeofday()
```

Every row carries `t_ms` (monotonic since boot, always correct). `iso_utc` is **empty** until `TIME`
is sent, and flag `0x0080` says so. An empty column is the truthful answer; a fabricated timestamp
is not.

### 5.3 CSV

`#`-prefixed header block (firmware version, session, full condition set, calibration constants,
safety ceilings), then `#COLS`, then rows. Everything in `analysis/` already skips `#`.

```
t_ms,iso_utc,sess,cond_id,activity,total_n,ch0_n,ch1_n,ch2_n,ch3_n,
cop_ap_mm,cop_ml_mm,bw_ratio,fsr0_adc,fsr0_mv,fsr1_adc,fsr1_mv,flags
```

`activity` = the posture verbatim, which is the column `analysis/balance.py`'s `group_col()` looks
for. `fsr*_adc` is raw 12-bit, the column `analysis/calibrate.py` expects; `fsr*_mv` is
`analogReadMilliVolts()` — better linearity, added *alongside* rather than replacing, so the existing
fit still runs unchanged.

SD path: `/plog/S<session>_C<cond_id>.csv`, flushed every 20 rows so a yanked card loses ≤20 rows.

**⚠️ microSD does not work today and that is a parts gap, not a code gap.** A 32 GB SanDisk card is
on hand (`INVENTORY.md:554`) but **no microSD breakout / card socket is owned** — there is no such
row anywhere in the inventory, which is exactly what `POST_RESTART_CART.md:382` logged as **T1-05,
~$3.50, "cheapest structural unblock in the file."** The firmware detects this and prints
`#WARN no microSD ... serial only`, then runs normally on serial. Piping serial to a file works today.

### 5.4 `flags` bitmask

| Bit | Meaning |
|---|---|
| `0x0001` | HX711 read timeout |
| `0x0002` | HX711 saturated (rails at ±0x7FFFFF → usually a disconnected cell or no excitation) |
| `0x0004` | **overload trip** |
| `0x0008` | not tared |
| `0x0010` | not calibrated (scale factor still 0) |
| `0x0020` | condition incomplete |
| `0x0040` | SD write failure |
| `0x0080` | wall clock never set |
| `0x0100` | session cap reached |

---

## 6. Bench test — prove it works BEFORE anything is worn or loaded

Run in order. Any step that fails stops the sequence.

| # | Step | Pass criterion |
|--:|---|---|
| 1 | Flash, open serial 115200 | Banner prints, including **BENCH ONLY — DO NOT STAND ON THIS RIG** |
| 2 | `ID` | Pin map matches §3.2 exactly |
| 3 | **Meter before power.** With the AstroAI TRMS: HX711 `VCC` = 3.3 V, `E+`−`E−` ≈ 3.3 V, no continuity `VCC`↔`GND` | as stated |
| 4 | `RAW`, touch nothing | `ch0` counts present and *stable to a few hundred*. `TIMEOUT` = wiring fault, stop |
| 5 | `RAW`, press the rig by hand | counts move **monotonically** with press. If they move backwards, `A+`/`A−` are swapped |
| 6 | `ZERO` (60 s, untouched) | spread **< 2 N**. If not, keep warming up and repeat |
| 7 | `TARE`, then `SHOW` | offset non-zero, flag `0x0008` cleared |
| 8 | `CAL 0 3.78` with a 1 gal water jug | accepted (>1000 counts). If refused, the reference is too light — that refusal is the firmware working |
| 9 | Remove mass, `RAW` | returns to within ~1 N of zero. A large residual = mechanical binding, **not** a code problem |
| 10 | Re-place the same mass **5×**, note the reading | spread **< 2 %** of the value. This is the repeatability number that decides whether the rig is usable at all |
| 11 | `SAVE`, reset the board, `SHOW` | calibration survived the reboot |
| 12 | `START` with **no** condition set | **refused**, with the coordinates message. This test proves the gate works |
| 13 | `COND ...` then `START` | header block + CSV rows stream |
| 14 | Press past ~25 kg | `#ALERT OVERLOAD`, logging stops, LED solid. **This is the safety test — do not skip it.** Send `CLEAR` |
| 15 | Unplug the HX711 mid-session | `#FAULT ... timed out`, clean stop. **No hang.** This is the watchdog/timeout test |
| 16 | Press the `fsr_puck` on FSR A | `fsr0_adc` / `fsr0_mv` rise and return |

Steps **14 and 15 are the ones that matter most** and are the easiest to skip. 14 proves the hard
limit fires; 15 proves a fault presents as a fault rather than as a plausible-looking flat line.

---

## 7. Compile state — measured, 2026-08-07

Compiler: bundled `arduino-cli 1.5.1`
(`AppData\Local\Programs\Arduino IDE\resources\app\lib\backend\resources\arduino-cli.exe`),
esp32 core **3.3.11**. **No library installs were performed.**

```
arduino-cli compile --fqbn esp32:esp32:esp32 firmware/force_plate
```

| Build | Program storage | RAM |
|---|--:|--:|
| `force_plate` `MODE_TOTAL` (default) | **376,845 B / 28 %** | 24,368 B / 7 % |
| `force_plate` `MODE_AP` (`-DACQ_MODE=1`) | 377,369 B / 28 % | 24,368 B / 7 % |
| `force_plate` `MODE_COP4` (`-DACQ_MODE=2`) | 378,017 B / 28 % | 24,368 B / 7 % |
| `fsr_calibrate` `FSR_DIRECT` (`adafruit_feather_esp32c6`) | 294,110 B / 22 % | 15,500 B / 4 % |
| `fsr_calibrate` `FSR_MUX` (`-DFSR_MODE=1`) | 294,380 B / 22 % | 15,500 B / 4 % |

All five clean, no warnings-as-errors. **All five are UNTESTED ON HARDWARE.**

---

## 8. Parts this needs that are NOT verified on hand → CART

Ordered by what unblocks the most for the least. **Nothing here has been ordered, carted or paid for.**

| # | Part | ~$ | Unblocks | Evidence it is missing |
|--:|---|--:|---|---|
| **1** | **microSD breakout / SPI card socket** | 3.50 | on-device logging for this *and* every worn node. The 32 GB card is already owned | **No such row exists anywhere in `INVENTORY.md`.** Logged as T1-05 in `POST_RESTART_CART.md:382`, "cheapest structural unblock in the file" |
| **2** | **Breadboard + jumper wires** | ~8 | *every* "solderless bench" claim in this repo, including step 4 of §6 | `INVENTORY.md:162` — explicitly NOT owned |
| **3** | **22 AWG silicone stranded** — ⚠️ **already carted, not ordered** | 15.69 | the in-shoe FSR run and the force-plate harness. `INVENTORY.md:577` scopes it to *"the bed mat + force plate only"* — this subsystem is one of the two things it is actually for | `:156` NOT owned; TUOFENG `B07G2JWYDW` in the **active cart** since 2026-08-07. Rank **14 of 16** in `CONSTRUCTION_ORDER.json` — do not call it the top blocker |
| **4** | **Reference masses or a hanging/fish scale, ≥10 kg** | ~12 | **turns every reading in this repo from arbitrary units into newtons.** §4 step 6 | `MASTER_REGISTER.md:1001` item 4-6 T2, "a reference force above 200 g" |
| **5** | **HX711 amplifier ×3** | ~9 | `MODE_COP4` — full 2-D centre of pressure. *This is the open $9 question, and the answer is that CoP is not possible without it* | only **1 set** owned (`INVENTORY.md:259`) |
| **6** | **4× full-bridge (4-wire) load cells** | ~15 | `MODE_COP4` needs full bridges; the owned kit is half-bridge | owned kit is the 4×50 kg half-bridge type |
| **7** | **M2–M6 fastener assortment (incl. M5)** | ~8 | mechanically assembling *any* foot to *any* cell — `force_plate.scad` `LC_hole_d = 5.2` is M5 clearance. **This is rank 13 in `CONSTRUCTION_ORDER.json`, the tree's top purchase blocker** | **zero** screw/bolt/nut/washer rows in `INVENTORY.md`; 345 heat-set inserts have nothing to thread into |
| **8** | PA-CF or PETG-CF filament for the structural reprint | — | reprinting 4 feet + 4 bosses to `PRINT_CARD.md:40` spec | plain PETG at ≤52 % density is a fit coupon, not a load path |
| **9** | USDRWAM thin-film FSR ×4 | 9.99 | 6 owned + 4 = 10 = one full single-foot map | **evicted to Saved-for-Later**, `INVENTORY.md:569` — will not arrive unless moved back |

**Cheapest path to a fully working logger today: #1 alone ($3.50).** Everything else in this folder
already runs on serial with what is on the shelf.

### ⚠️ Shelf check owed before any of this is trusted

`INVENTORY.md` contradicts itself about the load cells **right now**: `:157` "NOT owned" (the phantom
$471.94 order that was never placed), `:310` still an open ~$12 buy line, `:344` "force plate ⛔
BLOCKED", against `:563` "on-hand, sensor batch delivered Aug 1–2". The later reconciliation is
probably right — but the **Velostat from that same batch is still in transit (ETA ~Aug 10)**, so the
batch demonstrably did not fully land, and unlike the multimeter and coin motors ("verified on
arrival") the load cells got no arrival check and appear in no photo. `FIRMWARE_SCOPE.md:65` declared
this settled citing `INVENTORY.md:474` — **that citation is now dead** (line 474 is a filament row).

**Opening the box is the cheapest action in this entire tree and it gates §6 step 4 onward.**

---

## 9. Safety, stated plainly

* **Nothing in this subsystem heats, vibrates or moves.** No motor, no heater, no servo, no haptic.
  The only output pin is the 3 mA status LED. There is therefore no duty cycle to bound — that is the
  honest answer, not an omission. The HX711 excites the bridge at ~4.3 V through ~1 kΩ (~4 mA); there
  is no thermal path to skin in this circuit at all.
* **Hard input limit, latching:** `MAX_BENCH_N = 250 N`. Trips → alert, session stops, requires
  `CLEAR`. ~25 kg is far above any legitimate bench mass and far below the ~779 N one sole sees.
* **Session cap:** 20 minutes, auto-stop. Bounds an unattended rig pressing on an insensate foot.
* **Task watchdog:** 8 s, panic on timeout, fed every loop. Every HX711 read is timeout-guarded, so a
  missing amp reports `#FAULT hx711_timeout` instead of hanging in a way that looks like "no load".
* **`ALLOW_BODY_LOAD` is 0** and should stay 0 until the rig is reprinted to structural spec *and*
  proof-loaded. Note the proof load cannot currently be done at all: the owned 4× 50 kg cells sum to
  ~1.96 kN against a ~3.5 kN target (`force_plate.scad`).
* **T1DM + hEDS are why these are in code rather than in prose.** Reduced protective sensation means
  a fault may not be felt; a foot injury here is not a bruise.

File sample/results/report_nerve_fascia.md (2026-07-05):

# Nerve & fascia load — from the all-day pressure dose
_Which nerves/fascia your day's loading overloads, via **CPTS = PTI × cycles/day** (gait steps + the at-rest bounce dose) and the pressure gradient. Associations published (refs/plantar_norms.json `structures`); zone weights estimated. **SCREENING/EDUCATION, NOT A DIAGNOSIS** — these structures overlap & mimic each other._

**Daily dose (CPTS, MPa·s/day):** forefoot **12783** · heel/mid **4337**   _(diabetic-ulcer healing anchor 140–275; an order-of-magnitude reference for AT-RISK tissue, not a healthy-foot limit — use it to compare zones & track your own trend)._
> ⚡ **55% of the forefoot's daily loading cycles come from the at-rest bounce/tap dose** (40,320/day vs 33,622 gait) — invisible to any step-counter, landing on the same met heads gait already loads.

| structure | kind | load (CPTS) | | driving zones | peak | Δgrad |
|---|---|---|---|---|---|---|
| **plantar_fascia** | fascia | 11688 | ████████████ 🔴 HIGH | heel_med, met1, met2, met3, hallux, toes | heel_med 645 kPa | 556 kPa |
| **morton_neuroma** | nerve | 6584 | ███████ 🟠 elevated | met2, met3, met4 | met3 263 kPa | 174 kPa |
| **tibial_nerve_tarsal_tunnel** | nerve | 5004 | █████ 🟠 elevated | heel_med, midfoot, met1 | heel_med 645 kPa | 556 kPa |
| **baxter_nerve** | nerve | 2395 | ██ 🟢 watch | heel_med | heel_med 645 kPa | 556 kPa |

## What's driving each (mechanism · clue · manage)

### plantar_fascia  ·  fascia  ·  🔴 HIGH
- _aka_ plantar aponeurosis
- **mode:** tension (windlass) + insertional compression
- **driver:** heel-lift + toe/hallux extension tensions it; equinus/tight gastroc forces early forefoot loading and raises met-head pressure -> more fascial tension. Toe-walking/forefoot-loading stacks the dose.
- **tell it apart:** medial calcaneal insertion; classic FIRST-STEP MORNING pain, worse after rest.
- **manage:** offload medial heel AND cushion the forefoot; calf/soleus length work; hallux/windlass load management. Hypermobile: load, don't over-stretch.
- load 11688 MPa·s/day from heel_med, met1, met2, met3, hallux, toes; peak heel_med 645 kPa; steepest gradient 556 kPa. _Sources: [pf_windlass](https://pmc.ncbi.nlm.nih.gov/articles/PMC385265/), [equinus_pf](https://www.michiganfootdoctors.com/gastrocnemius-recession-equinus-contracture-plantar-fasciitis/)._

### morton_neuroma  ·  nerve  ·  🟠 elevated
- _aka_ interdigital / intermetatarsal neuroma (common digital plantar nerve)
- **mode:** compression between met heads + toe-hyperextension tethering under the transverse intermetatarsal ligament
- **driver:** forefoot loading + toe extension. The at-rest forefoot BOUNCE/toe-tap dose (bounce.py) stacks onto gait here -- narrow 2nd/3rd interspaces already run higher pressure.
- **tell it apart:** BURNING / numbness / tingling into adjacent toes, 'pebble in the shoe', Mulder's click; relieved by removing the shoe & splaying the toes.
- **manage:** widen the toe box, a metatarsal pad PROXIMAL to the met heads to splay them, cut forefoot dose / add ball-of-foot rest windows, avoid sustained toe-hyperextension.
- load 6584 MPa·s/day from met2, met3, met4; peak met3 263 kPa; steepest gradient 174 kPa. _Sources: [morton](https://www.ncbi.nlm.nih.gov/books/NBK470249/), [press_grad](https://pmc.ncbi.nlm.nih.gov/articles/PMC2387244/)._

### tibial_nerve_tarsal_tunnel  ·  nerve  ·  🟠 elevated
- _aka_ posterior tibial nerve (tarsal tunnel, medial ankle)
- **mode:** tension/traction with overpronation (medial-column collapse)
- **driver:** an overpronation / medial-loading signature (heel_med >> heel_lat, heavy medial midfoot) puts the nerve under traction at the medial ankle.
- **tell it apart:** medial-ANKLE Tinel; burning/tingling radiating into the sole & toes; worse with activity/standing.
- **manage:** medial-arch support / motion control to reduce pronation traction; if radiating medial-ankle symptoms -> clinician.
- load 5004 MPa·s/day from heel_med, midfoot, met1; peak heel_med 645 kPa; steepest gradient 556 kPa. _Sources: [tarsal_tunnel](https://www.ncbi.nlm.nih.gov/books/NBK513273/)._

### baxter_nerve  ·  nerve  ·  🟢 watch
- _aka_ inferior calcaneal nerve = first branch of the lateral plantar nerve
- **mode:** compression (entrapment under abductor hallucis / thickened fascia / spur)
- **driver:** sustained medial-heel weight-bearing dose through the day; a thickened/inflamed plantar fascia squeezes it.
- **tell it apart:** pain slightly MORE MEDIAL than the fascia insertion; unlike fasciitis it WORSENS THROUGH THE DAY with weight-bearing (an all-day-dose signature), often burning/constant; Tinel over the medial calcaneus radiates to the lateral heel / 4th-5th toes.
- **manage:** the same medial-heel offload helps, but if heel pain is worse-with-the-day (not worse-in-the-morning) and resists fasciitis care, this nerve is the suspect -> clinician for US-guided block / MRI.
- load 2395 MPa·s/day from heel_med; peak heel_med 645 kPa; steepest gradient 556 kPa. _Sources: [baxter](https://radsource.us/baxters-nerve/)._

## Reads
- **Forefoot dominates the day's dose** → interdigital-nerve (Morton) + met-head load is the biggest cumulative exposure. The bounce dose is a big, hidden part of it — dose it, don't just suppress it: metatarsal pad, wider toe box, ball-of-foot rest windows.
- **Medial heel pain? Time-of-day tells fascia from nerve:** plantar fasciitis = worst first steps in the **morning**; Baxter's nerve = worse **as the day's weight-bearing accumulates**. Same spot, different fix — log when it hurts.
- **Steep forefoot pressure gradient at met3 (174 kPa jump)** → concentrated subsurface shear near the digital nerves (gradient discriminates breakdown risk better than peak alone). Smooth it with a met pad / cushioning that spreads the load.

---
_Not a medical device; not medical advice. A screening/education aid to discuss with a clinician — confirming which nerve or fascia is involved usually needs exam + ultrasound/MRI or a diagnostic block. Structures & mechanisms: refs/plantar_norms.json `structures`._

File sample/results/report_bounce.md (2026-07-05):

# At-rest forefoot dose — leg-bounce / toe-tap

- **Bouncing detected: 2.8 Hz** (toe-tap band; 100% of the signal's motion).
- **168 forefoot cycles** this 60s session.
- Projected **40,320 forefoot loading cycles/day** at 4 h/day —
  **≈ 5.8× a typical day's walking steps (7,000).** This is the HIDDEN dose no step-counter sees.
- Forefoot **pressure-time integral (dose): 22807 rel·s** this session → ~5,474,498 rel·s/day.

_For a forefoot-loader (toe-walking / equinus), this stacks ON TOP of gait — the ball of the foot never gets a rest. Options: vary the pattern, a soft forefoot pad while seated, or a different fidget outlet. Not a reason to suppress a self-regulating movement — just to dose it._

_(Relative units — add --calibration for the dose in real kPa·s.)_

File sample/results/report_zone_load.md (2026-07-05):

# Zone load vs norm — equinus
_limited ankle dorsiflexion (tight gastroc/Achilles) during gait. Athlete regional load vs the field's reference (refs/plantar_norms.json). met2/met4 interpolated. Not a medical device._

| zone | you % | norm % | ratio | |
|---|---|---|---|---|
| heel_med | 2.4 | 8 | 0.3 | 🔵 under |
| heel_lat | 2.4 | 6 | 0.4 | 🔵 under |
| midfoot | 2.4 | 6 | 0.4 | 🔵 under |
| met1 | 20.5 | 15 | 1.37 | 🔴 OVER |
| met2 *(interp)* | 21.3 | 16 | 1.33 | 🔴 OVER |
| met3 | 22.1 | 14 | 1.58 | 🔴 OVER |
| met4 *(interp)* | 13.0 | 8 | 1.62 | 🔴 OVER |
| met5 | 4.0 | 6 | 0.67 | 🔵 under |
| hallux | 4.0 | 9 | 0.44 | 🔵 under |
| toes | 7.9 | 6 | 1.32 | 🔴 OVER |

**Over-used** (≥1.3× the norm): met1 (1.37×), met2 (1.33×), met3 (1.58×), met4 (1.62×), toes (1.32×)
  · **met1** at ~(x 28, y 184) mm on your 255 mm foot — 1st metatarsal head (+ sesamoids)
  · **met2** at ~(x 38, y 189) mm on your 255 mm foot — 2nd metatarsal head (longest; #1 stress-fx site)
  · **met3** at ~(x 48, y 191) mm on your 255 mm foot — 3rd metatarsal head
  · **met4** at ~(x 57, y 189) mm on your 255 mm foot — 4th metatarsal head
  · **toes** at ~(x 53, y 245) mm on your 255 mm foot — lesser toes
**Under-used** (≤0.7× the norm): heel_med (0.3×), heel_lat (0.4×), midfoot (0.4×), met5 (0.67×), hallux (0.44×)
🩺 **Management:** restore dorsiflexion to drop forefoot pressure. Tight NON-hypermobile calf -> eccentric/mobilize; HYPERMOBILE -> LOAD/strengthen (a lax system needs control, not more stretch); severe/resistant -> gastroc recession is the surgical option.

🔗 **Kinetic chain (it's all connected to the foot):** the common thread behind toe-walking + heel-pain avoidance; drives PF + forefoot problems

⚠️ **Injury-relevant overload at met2, met3** — metatarsalgia, met stress fx, plantar plate tear, sesamoiditis, plantar fasciitis (forefoot overload from restricted dorsiflexion)
→ Load has shifted **off the hallux onto the central met heads** — the published 1st-MTP-pain pattern; central-met (2nd-met) overload is the 'dancer's fracture' route. Cue big-toe engagement / check the 1st ray.

_Reference peak force for this movement: **1.2× BW** (range ?, estimated). Add --calibration + --bodyweight-kg to compare yours._
_Caution: 200 kPa in-shoe / [450, 750] kPa barefoot are **at-risk/neuropathic** ulcer thresholds — healthy athletic tissue tolerates far higher transiently._

_Distribution basis: estimated (<10 deg dorsiflexion -> premature heel rise -> forefoot overload) — Ankle-joint flexibility & barefoot plantar pressures, healthy older adults (PMC9338503) (https://www.ncbi.nlm.nih.gov/pmc/articles/PMC9338503/)._

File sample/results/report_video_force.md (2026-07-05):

# Video -> force estimate

## Limb asymmetry
- Left 4.6× vs right 3.7× BW → **20% asymmetry** — ⚠ >10-15% is a non-contact ACL precursor (acl_asym); train the weaker limb.

_Estimation via the single-body CoM model / impulse; pose→GRF basis: Estimation of vGRF in single-leg landing from 2D video + pose-estimation AI, 2024 (https://www.ncbi.nlm.nih.gov/pmc/articles/PMC11057390/). Estimate, not a measurement. Not a medical device._

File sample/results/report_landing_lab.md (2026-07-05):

# Landing lab — discipline-aware landing scores
_All land forefoot-first; the discipline decides what 'good' means. From the insole COP + IMU._

## dance_landing — dance  ·  **9.9/10** (soft & rolled)

- toe->ball->heel roll: yes (heel 0.85s after forefoot)
- impact soft (loading rate 2692 N/s) · demi-plié absorbs it

## gymnastics_stick — gymnastics  ·  **9.8/10** (STUCK — clean)

- settle 0.39s · 2 wobble(s) · step no
- forefoot-first then heel, then hold — that's the stick.

## skating_checkout — figure skating  ·  **9.7/10** (clean edge check-out)

- landed on the outside/lateral edge · edge chatter (ML std) 0.5 mm
- forward flow-out 14.4 mm (smooth glide) · absorption soft plié

_Gymnastics rewards stopping; skating rewards a clean gliding edge; dance rewards a soft roll. Same sensor, three rubrics. Sync each rep to your video by timestamp._

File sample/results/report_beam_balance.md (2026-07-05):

# Beam / athlete balance — findings
_Elite balance: mediolateral control + landing 'stick'. From the insole COP + IMU._

## landing_clean — landing  ·  **stick 10.0/10** (STUCK — clean)

- settle 0.0s · post-sway 0 mm² · 0 wobble(s) · ML swing 0.6 mm · step: no
- execution deduction ~0.0 pt

## landing_wobble — landing  ·  **stick 9.2/10** (small check)

- settle 0.94s · post-sway 5 mm² · 2 wobble(s) · ML swing 5.6 mm · step: YES
- execution deduction ~0.8 pt

## releve_hold — hold  ·  **ML sway 0.42 mm (elite)**

- area 5.4 mm² · vel 2.9 mm/s · held 8.0s
- load: 92% forefoot / 0% heel (relevé — on the ball)

_On a beam, watch ML sway (not total). A clean stick is ≥9.7; each wobble ~0.1, a step ~0.5. Trend these across a season._

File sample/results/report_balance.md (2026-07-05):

# Balance / posturography — findings
_Sway from center-of-pressure + IMU. A screening / training aid, not a diagnosis._

## eyes_closed

- Sway ellipse area 770.1 mm^2, path 1086.2 mm over 30.0 s (velocity 36.2 mm/s).
- **Elevated sway area** — reduced postural stability; a fall-risk screen is warranted.
- **High sway velocity** — many fast corrections (fatigue / vestibular / proprioceptive contribution possible).
- Instability is **front-to-back (anteroposterior)** — ankle strategy / heel-toe support.
- Trunk sway (IMU) 0.167 — moderate.

**Flags:** large sway area, high sway velocity

## eyes_open

- Sway ellipse area 211.4 mm^2, path 934.6 mm over 30.0 s (velocity 31.2 mm/s).
- **High sway velocity** — many fast corrections (fatigue / vestibular / proprioceptive contribution possible).
- Instability is **front-to-back (anteroposterior)** — ankle strategy / heel-toe support.
- Trunk sway (IMU) 0.047 — moderate.

**Flags:** high sway velocity

## Romberg

- Romberg quotient (eyes-closed / eyes-open sway area) = 3.6. **>2 -> strong reliance on vision** (proprioceptive/vestibular deficit pattern).

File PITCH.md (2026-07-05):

# A $100 wearable that does what a $5k+ gait lab does — all day

**biomech-pressure-lab** turns a hobby 3D printer + ~$100 of electronics into a
wearable that (1) finds exactly where your foot is overloaded and **prints a
custom relief insole from the data**, and (2) doubles as a **balance / fall-risk
screen** — worn all day, not for one 10-second snapshot in a clinic.

---

## The problem
- **Foot pain** is treated by feel: heel pads, generic orthotics, "try this and
  see." Clinical **pressure plates** that actually *measure* load cost **$5k–40k**,
  live in a clinic, and capture a few steps.
- **Balance issues** (fall risk, vestibular/proprioceptive) are screened on
  **force plates / posturography rigs** — same story: expensive, in-clinic, brief.
- Neither follows you into a real day, a real shoe, a real floor.

## The solution
One small **ankle pod** (ESP32 + battery + microSD + motion sensor) and a
**paper-thin sole** with 8 force sensors. Electronics ride at the ankle — nothing
bulky underfoot. Log a normal day (shoe *and* barefoot), pull the card at night,
and the software tells you where the load is and **prints the fix**.

measure → design → print → re-measure

## It works today — a committed worked example
Run on a synthetic day of data (in [`sample/`](sample/README.md), reproduces in ~5 s):
- Calibration fits real physics → **R² = 1.00**, readings in **real kPa** (not "relative").
- Hot spot at **heel_med — 645 kPa, 40 % of load**; **medial pronation**; the *shoe
  adds +13 pts* vs barefoot.
- `build_insole.py` reads those findings and emits a **print-ready insole**
  ([relief_insole.stl](hardware/relief_insole.stl)) — aggressive medial-heel relief,
  medial post, heel cushion — no hand-editing.

two software modules

## Two capabilities, one rig
| | Pressure module | Balance module |
|---|---|---|
| **For** | foot pain / custom insoles | balance issues / fall risk |
| **Measures** | peak, impulse, COP, medial/lateral, cadence (kPa) | sway area, velocity, ML/AP, **Romberg** |
| **Worked-example result** | heel_med 645 kPa → aggressive relief insole | eyes-open 211 → closed 770 mm², **Romberg 3.6** |
| **Output** | a printed relief insole | a fall-risk screen + device class |

## Cost
| | ~$ |
|---|---|
| Electronics rig (ESP32-S3, 8× FSR, mux, IMU, microSD, LiPo, charger, ribbon) | **~100** |
| Bambu **H2D** + TPU High-Flow kit (prints the insoles + the pod) | ~1,730 |
| TPU filament (soft 85A + firm 95A) | ~74 |
| **Per printed insole after that** | ~cents |

## Status
- ✅ **Software + design: done & verified** — firmware (all-day logger), calibration,
  pressure + balance analysis, the auto-insole generator, print-ready STLs, and a
  self-demonstrating worked example are all committed.
- ⏳ **Physical build**: order the rig, print the parts, solder, calibrate with known
  weights — once the printer lands. See [docs/prototype_status.md](docs/prototype_status.md).

> **Not a medical device** — a design / screening / training aid. Pair with a
> podiatrist or clinician for pain and fall risk. DIY FSR insoles validate to
> r ≈ 0.87 vs professional systems — plenty for *relative* mapping and trend.

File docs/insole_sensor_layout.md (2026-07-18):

# FSR sensor layout — the 6-zone STEMMA-QT rig

Zone coordinates for the updated Path 2 electronics: **ESP32-C6 Feather + 6× FSR402**, no mux.
Companion to [`hardware/insole_fsr_layout.scad`](../hardware/insole_fsr_layout.scad) (the flat
carrier plate) — read them together. This doc gives the numbers; the `.scad` turns them into a
printable part.

> This is a **6-zone variant** of the repo's existing 8-zone scheme (see `ZONES` /
> `SENSOR_XY` in [`analysis/analyze_pressure.py`](../analysis/analyze_pressure.py) and the
> `zones` array in [`hardware/barefoot_sole.scad`](../hardware/barefoot_sole.scad)). Same
> coordinate convention, same zone names, just **met3 and toes dropped**. That's not an
> accuracy compromise picked at random — it's sized to the hardware: the ESP32-C6 Feather
> exposes exactly **six** analog-capable pins (`A0`–`A5`), so 6 FSRs wire straight in with no
> multiplexer, one sensor per pin. The 8-zone rig needs a `CD74HC4067` mux for that reason; this
> one doesn't. If you want the finer 8-zone map later, add the mux back (same part as the
> existing rig) and go back to the full `ZONES` list — the FSR 10-pack has the sensors for it
> already, this is a wiring-simplicity choice, not a hardware ceiling.

## Zones — normalized position

Same `[x medial→lateral, y heel→toe]` fractions used elsewhere in the repo (0..1 each), and the
wiring order they land on (`fsr0`..`fsr5` → `A0`..`A5` on the Feather):

| # | Zone | x_frac | y_frac | Feather pin |
|---|---|---|---|---|
| 0 | `heel_med` | 0.35 | 0.08 | `A0` |
| 1 | `heel_lat` | 0.65 | 0.08 | `A1` |
| 2 | `midfoot`  | 0.50 | 0.45 | `A2` |
| 3 | `met1` | 0.30 | 0.72 | `A3` |
| 4 | `met5` | 0.70 | 0.72 | `A4` |
| 5 | `hallux` | 0.28 | 0.92 | `A5` |

`x_frac` is measured across a **`FOOT_W`-wide band centered under the foot** (medial edge = 0),
not the full shoe width; `y_frac` is measured heel-back-edge (0) to toe (1) along the foot's long
axis. This is the same simplification `analysis/zone_load.py`'s `zone_mm()` and
`hardware/barefoot_sole.scad` already use — one width value for the whole foot, not a per-row
taper.

## Coordinates in mm — worked example, men's ~US10

```
FOOT_LEN = 267 mm                          # men's ~US10 (~10.5"); ±5 mm across shoe-size charts
FOOT_W   = FOOT_LEN × (95 / 255) ≈ 99.5 mm  # same length:width ratio as refs/plantar_norms.json's
                                             # reference foot — the repo's existing norms-DB ratio
x_mm = x_frac × FOOT_W
y_mm = y_frac × FOOT_LEN     # from the heel's back edge
```

| Zone | x (mm, from medial edge) | y (mm, from heel) |
|---|---|---|
| `heel_med` | 35 | 21 |
| `heel_lat` | 65 | 21 |
| `midfoot`  | 50 | 120 |
| `met1` | 30 | 192 |
| `met5` | 70 | 192 |
| `hallux` | 28 | 246 |

## Scaling to your own foot

Two options, same as [`docs/fit_to_your_foot.md`](fit_to_your_foot.md):

1. **Just change `FOOT_LEN`** in `hardware/insole_fsr_layout.scad` (or the formula above) — width
   rescales automatically off the 95:255 ratio. Fastest, ~90% accurate.
2. **Use your real measurements** — if you've already measured `length` / `forefoot-width` for
   `build_insole.py` (docs/fit_to_your_foot.md §Level 2), reuse those directly instead of the
   derived ratio: `x_mm = x_frac × your_forefoot_width_mm`, `y_mm = y_frac × your_length_mm`.
   Closer fit if your foot is unusually narrow/wide for its length.

## Compatibility note for the analysis scripts

`analyze_pressure.py`, `zone_load.py`, `day_summary.py`, `nerve_fascia.py`, and
`make_sample_data.py` all currently expect **8** FSR columns (`ZONES`/`SENSOR_ZONES` includes
`met3` and `toes`). Logs from this 6-zone rig only have `fsr0..fsr5`. Two ways to reconcile —
neither is done yet, flagged here the same way `path2_tracking_build.md` flags its own
`mode`-column TODO:
- **Quick:** zero-fill (or interpolate, like `zone_load.py` already does for `met2`/`met4`) the
  missing `met3`/`toes` columns before feeding a log into the existing scripts.
- **Clean:** edit the `ZONES` list at the top of each script to the 6-zone set in the table
  above and drop the `met3`/`toes` references. Small, mechanical change — same pattern as adding
  the mux back if you upgrade to 8 zones later.

## Printing

[`hardware/insole_fsr_layout.scad`](../hardware/insole_fsr_layout.scad) turns this table into a
part — either a thin TPU wearable carrier, or a quick PLA layout jig to trace the zones onto a
shoe/orthotic by hand. Pockets are sized for the same
[`hardware/fsr_puck.scad`](../hardware/fsr_puck.scad) force-concentrator used elsewhere in the
repo. Full print settings + assembly order: [`BUILD_PLAN.md`](BUILD_PLAN.md).

Not a medical device — a build reference, same as the rest of `docs/`.

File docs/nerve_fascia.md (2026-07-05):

# From foot pressure → nerve & fascia impact

The insole gives a pressure map. This layer asks the next question: **given the load your foot
takes *all day*, which nerves and fascia are being overloaded — and how would you tell them
apart?** It's the bridge from a number on a sensor to a structure that can hurt.

Module: [`analysis/nerve_fascia.py`](../analysis/nerve_fascia.py) (`--demo`). Structures + citations
live in [`refs/plantar_norms.json`](../refs/plantar_norms.json) under `structures`.
**Screening / education, not a diagnosis** — these structures overlap and mimic each other.

Nerve & fascia map

## The metric that connects pressure to tissue: CPTS

Peak pressure is *one step*. The pressure-time integral (PTI) is *one step's dose*. **Cumulative
Plantar Tissue Stress** is a whole **day's** dose — and the day's dose is what overloads tissue:

> **CPTS = PTI × loading-cycles-per-day**  (MPa·s/day)

It predicts diabetic-ulcer healing better than pressure or activity alone (healed vs non-healed:
**140 vs 275 MPa·s/day**), and higher CPTS tracks joint pain too. → [CPTS & ulcer healing](https://pubmed.ncbi.nlm.nih.gov/29477099/),
[CPTS & first-MTP pain](https://pmc.ncbi.nlm.nih.gov/articles/PMC5473430/).

The key move for **our** rig: **forefoot cycles/day = gait steps + the at-rest leg-bounce/toe-tap
dose** that [`bounce.py`](../analysis/bounce.py) counts. In the demo that at-rest dose is **~85% of
the forefoot's daily loading cycles** — a habit no step-counter sees, landing on the exact met
heads gait already loads. That's why the forefoot nerve/fascia load dominates the day.

*(Anchor caveat: 140–275 MPa·s/day is a **diabetic-ulcer** figure — an order-of-magnitude
reference for at-risk tissue, not a healthy-foot limit. Use CPTS to compare your zones and track
your own trend, not as a cutoff.)*

## Bonus signal: the pressure gradient

A steep spatial **gradient** (a sharp pressure jump right next to a hot zone) concentrates
*subsurface shear* near nerves and soft tissue — and it discriminates breakdown risk better than
peak pressure alone, especially in the forefoot where shear sits closest to the surface. →
[Pressure gradient & subsurface shear](https://pmc.ncbi.nlm.nih.gov/articles/PMC2387244/). The
module flags forefoot gradient hotspots.

## The structures it maps

| Structure | Kind | Loaded by | Mode | Tell it apart | Source |
|---|---|---|---|---|---|
| **Plantar fascia** | fascia | heel_med + forefoot/hallux (windlass) | **tension** + insertional | first-step **morning** pain, medial calcaneus | [windlass](https://pmc.ncbi.nlm.nih.gov/articles/PMC385265/) · [equinus](https://www.michiganfootdoctors.com/gastrocnemius-recession-equinus-contracture-plantar-fasciitis/) |
| **Baxter's nerve** | nerve | heel_med (medial) | compression / entrapment | worse **through the day**, Tinel → lateral heel | [Baxter](https://radsource.us/baxters-nerve/) |
| **Morton's / interdigital** | nerve | met2·met3·met4 | compression + toe-extension tether | **burning/numb toes**, Mulder's click | [Morton](https://www.ncbi.nlm.nih.gov/books/NBK470249/) |
| **Posterior tibial (tarsal tunnel)** | nerve | heel_med·midfoot·met1 | tension w/ overpronation | medial-**ankle** Tinel, radiating sole | [tarsal tunnel](https://www.ncbi.nlm.nih.gov/books/NBK513273/) |

## Condition-aware reads the module makes

- **The forefoot dose dominates, and the bounce habit is most of it** → interdigital-nerve
  (Morton) + met-head load is the biggest cumulative exposure. Manage the *dose*, don't just
  suppress the movement: metatarsal pad **proximal** to the heads, wider toe box, ball-of-foot
  rest windows.
- **Medial heel pain — let the clock diagnose:** plantar fasciitis is worst on the **first steps
  in the morning**; Baxter's nerve gets worse **as the day's weight-bearing accumulates**. Same
  spot, opposite time-signature, different fix. (Baxter's is up to ~20% of chronic heel pain and
  routinely missed.) Log *when* it hurts.
- **Tight calf / equinus is an amplifier:** it forces early forefoot loading (↑ met-head pressure)
  **and** tensions the fascia via the windlass — equinus carries **~23× the plantar-fasciitis
  risk**. So a forefoot-overload signature and heel-fascia pain travel together.

## Run it — on real captured logs

The honest version runs off your actual day, not a demo. [`analysis/day_summary.py`](../analysis/day_summary.py)
turns raw session CSVs (from [`firmware/all_day_logger`](../firmware/all_day_logger/all_day_logger.ino) —
short-press cycles the `phase` tag walk/stand/**bounce**) into the per-zone **peak, PTI-per-cycle,
and cycles/day**, splitting gait from at-rest bounce. Then `nerve_fascia.py` computes the dose:

```bash
# one command: raw logs -> day summary -> nerve/fascia impact
python analysis/nerve_fascia.py --logs "logs/*.csv" --calibration cal.json \
    --walk-hours 10 --bounce-hours 4 --out results/

# or in two explicit steps
python analysis/day_summary.py "logs/*.csv" --calibration cal.json --walk-hours 10 --bounce-hours 4 --out results/
python analysis/nerve_fascia.py --day results/day.json --out results/

python analysis/nerve_fascia.py --demo    # no hardware — the worked example
```

It runs on the committed sample end-to-end (see [sample/README](../sample/README.md) steps 5b–5c →
[report_nerve_fascia.md](../sample/results/report_nerve_fascia.md)). The **measured** per-zone PTI
already encodes any under-loading (a toe-walker's light heel reads low), so CPTS is
`gait PTI/cycle × gait cycles + bounce PTI/cycle × bounce cycles` — no fudge factor. Emits a ranked
structure report + JSON. `--day` also accepts a hand-written summary (`pressure_kPa` + `pti_kPa_s` +
`gait_steps_per_day` + `bounce_cycles_per_day`).

## It feeds the insole

`interpret.py` writes a `structure_target` into the insole spec, and
[`build_insole.py`](../hardware/build_insole.py) **acts on it**:
- **Morton's** target → a **metatarsal pad** proximal to the met heads (splays met2-4, offloads
  the interdigital nerve), plus a forefoot relief.
- **plantar fascia / tibial** target → auto-enabled **arch support** (windlass unload /
  anti-pronation traction).
- **Baxter's / fascia** medial-heel target → the aggressive medial-heel relief already carried
  by the hot-spot logic.

So the print follows the *structure*, not just the peak-pressure zone.

## Track it over time

The point of a dose model is watching your numbers **move**. [`analysis/trend.py`](../analysis/trend.py)
logs each day's CPTS per structure and charts the trend:

```bash
python analysis/trend.py record results/day.json --date 2026-07-05 --history results/cpts_history.jsonl
python analysis/trend.py chart  --history results/cpts_history.jsonl --out results/
python analysis/trend.py --demo --out results/     # ~6 weeks, forefoot dose falling after an intervention
```

A falling forefoot line after a met pad / rest-window habit is the intervention working; a rising
line says the dose is creeping back ([sample trend](../sample/results/report_trend.md)).

---
**Not a medical device; not medical advice.** Associations are published; the zone-weights the
module uses are *estimated* from anatomy + those papers. Confirming which nerve or fascia is
actually involved needs a clinician (exam + ultrasound/MRI, or a diagnostic anesthetic block).
This tells you where your *mechanical dose* is going so you can offload it and ask better questions.

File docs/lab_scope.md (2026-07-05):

# Personal-lab scope — catching up to the papers' equipment

The studies we cite ran on **$10k–30k+** kit. This is the honest map of what that kit is,
what we can **3D-print / DIY** to approximate it, and where the gaps genuinely stay.

lab scope

## What the papers used
| Class | Instruments | Spec / accuracy | ~Cost |
|---|---|---|---|
| **In-shoe pressure** | Novel **pedar** (capacitive), Tekscan **F-Scan** (resistive), Moticon, Loadsol | pedar RMSE **2.6 kPa** (best); F-Scan/resistive RMSE ~31 kPa (drift) | $10–30k |
| **Platform pressure** | Novel **emed** (2 sensors/cm²), Tekscan **MatScan** (1.4/cm²), RSscan **Footscan** | MatScan within **1.9%** of an AMTI plate | $10–40k |
| **Force plate (GRF)** | **AMTI**, **Kistler**, **Bertec** | 6-axis force + moments + CoP | $5–30k |
| **Shear stress** | tri-axial force transducers | 3-axis stress (cutting shear 312–463 kPa) | custom/research |
| **Motion → GRF** | **Vicon** marker mocap; or 2D-pose→GRF | validated | $$$ (mocap) / free (pose) |

Key finding: **capacitive (pedar) beats resistive** (Tekscan/FSR) — resistive sensors have
**hysteresis, creep, and drift** (sensitivity shifts over the first minute + long-term).
That's the accuracy tax our FSR rig pays, and why calibration matters ([FSR feasibility](https://www.researchgate.net/publication/335528169), [3 in-shoe systems](https://www.ncbi.nlm.nih.gov/pmc/articles/PMC4101558/)).

## What WE can build (3D-print + buy)
1. **FSR sensor insole** — *have it.* Resistive, 8 zones, `calib.py` power-law → kPa. Coarse
   + drifts, but **r≈0.87 vs pro** — fine for relative/trend mapping.
2. **Velostat pressure MAT (platform)** — a copper-tape **row×column matrix** sandwiching
   [Velostat](https://www.adafruit.com/product/1361) (~$4/sheet), read by an ESP32/Arduino via the mux. A
   maker build hit **~7000 cells, clearly resolving heel/arch/forefoot** ([Hackaday](https://hackaday.com/2017/10/29/hi-res-body-sized-pressure-sensor-mat/)). **3D-print the frame.** ~$40 in parts.
3. **Load-cell force plate (vertical GRF)** — **4× load cells + HX711** on a rigid **3D-printed/
   plywood** top → **vertical GRF in body-weights** (the landing numbers). Instrumented
   load-cell systems hit **ICC > 0.94** vs a force plate ([Loadsol vGRF](https://www.ncbi.nlm.nih.gov/pmc/articles/PMC12747385/)). ~$80.
4. **Video → force** — phone + pose AI → [`video_force.py`](../integrations/video_force.py). *Free.*
5. **Calibration** — known weights → [`calibrate.py`](../analysis/calibrate.py) (demo R²=1.0).

## Parts: print vs buy
| 3D-print (H2D) | Buy |
|---|---|
| ankle pod, sensor soles, insoles | ESP32-S3, 8× FSR, mux, IMU, microSD, LiPo (**have in carts**) |
| **pressure-mat frame** + electrode jig | **Velostat sheet** (~$4) + copper tape + a bigger mux/ADC (16–32ch) |
| **force-plate top + 4 load-cell mounts/feet** | **4× load cells** (50 kg bar type) + **HX711** amp (~$15–25 total) |
| calibration weight tray | (use known weights / a bathroom scale as a check) |

Extra parts for the two new builds: **~$150–250** on top of the insole rig.

## The honest gaps (what we can't cheaply match)
- **Shear / 6-axis** — the cutting shear numbers need tri-axial transducers; **no maker-grade
  option.** Real gap.
- **Capacitive-grade accuracy + no drift** — pedar's 2.6 kPa RMSE; our resistive rig drifts →
  recalibrate, and read trends not absolutes.
- **Spatial density** — emed's 2 sensors/cm² vs our coarse zones (the Velostat mat narrows this
  but at lower accuracy).
- **Marker mocap** — Vicon 3D; we substitute 2D pose→GRF.

## Roadmap (priority for a one-person lab)
1. **Force plate first** (load cells + HX711 + printed top) — unlocks the **GRF/×BW** numbers
   (landings, jump, gym) that our insole can't, at ICC>0.94. Cheapest big win.
2. **Velostat mat** — a real full-foot pressure map (heel/arch/forefoot) to complement the
   8-zone insole; great for the standing/seated/bounce work.
3. Keep tightening **FSR calibration** (per-sensor, re-run when it drifts).
4. **Shear** stays parked — accept the gap, or revisit if a maker-grade 3-axis sensor appears.

**→ Build guides are written:** [`build_lab.md`](build_lab.md) — the printable force plate
([`force_plate.scad`](../hardware/force_plate.scad) + [firmware](../firmware/force_plate/force_plate.ino))
and Velostat pressure mat ([`pressure_mat.scad`](../hardware/pressure_mat.scad) +
[firmware](../firmware/pressure_mat/pressure_mat.ino)), with parts, wiring, and calibration.

Ethos: **r≈0.87, not 1.0.** A ~$250 lab that does what a ~$30k one does *at trend level* — which,
for finding *your* hot spots and dosing *your* load over time, is the measurement that matters.
Not a medical device.

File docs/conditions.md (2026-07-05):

# Condition-aware analysis — adaptive gait isn't an injury flag

Most tools assume a "normal" foot. Real people have **adaptive or altered baselines** —
heel pain, toe-walking, limited ankle motion. If you compare them to a textbook norm you
get false flags ("your heel is under-used!") that miss the point. So the engine can take
**your baseline as the reference**, then flag only the *real* risk.

condition-aware analysis

## The conditions (in `refs/plantar_norms.json`, cited)
| Condition | What the data shows | The engine's response |
|---|---|---|
| **Plantar fasciitis** (medial heel pain) | altered medial-heel pressure vector + forefoot/met overstrain; first-step morning pain ([PF gait](https://pmc.ncbi.nlm.nih.gov/articles/PMC5773441/)) | watch `heel_med`; offload the heel + restore ankle dorsiflexion |
| **Toe-walking** (idiopathic / adaptive) | **forefoot 61.7% / midfoot 15.3% / hindfoot 22.8%** vs normal ~39% / – / 30% ([ITW](https://pubmed.ncbi.nlm.nih.gov/31946390/)) | **low heel loading = the adaptive baseline, NOT a deficit**; track forefoot-overload trends + calf tightness |
| **Equinus** (< 10° dorsiflexion) | forefoot peak **677.8 kPa** vs **565.6** without equinus; premature heel rise ([ankle flexibility](https://www.ncbi.nlm.nih.gov/pmc/articles/PMC9338503/)) | forefoot overload → metatarsalgia / met stress / plantar plate / PF |

Autism-associated gait shows a forefoot-loading tendency and more L/R asymmetry; an
8-week program reduced medial-heel peak pressure and loading rate ([ASD](https://www.ncbi.nlm.nih.gov/pmc/articles/PMC9993582/)).

## Use it
```bash
# your baseline IS the profile (no false heel-deficit flag):
python zone_load.py --demo --profile toe_walking

# or a movement profile + your condition context:
python zone_load.py session.csv --profile running_forefoot --condition equinus --calibration cal.json
```
With `--condition` set to an **adaptive** pattern, heel under-use is annotated
*"expected — adaptive baseline, not a flag,"* and the report surfaces the condition's
published baseline, its **real** risks (forefoot overload, calf/Achilles), and a
person-specific management note.

## These loop together
Toe-walking, heel-pain avoidance, and equinus are one story: chronic plantarflexion
tightens the calf (equinus), which forces forefoot overload, which is what a toe-walker
already does — and avoiding a painful heel reinforces all of it. The engine watches the
**forefoot-overload trend + ankle dorsiflexion**, not the (expected) low heel.

> **Management is person-specific.** The textbook equinus fix is "stretch the calf" — but
> a **hypermobile** person usually needs **loading / strengthening**, not more stretch on
> an already-lax system. Reversing toe-walking isn't always the goal; if it's kept,
> protect the forefoot (met pad / cushion) and preserve ankle motion.

## At-rest matters too — the leg-bounce dose ([`analysis/bounce.py`](../analysis/bounce.py))
Foot tools only ever look at gait. But **leg-bouncing / toe-tapping** is repetitive
forefoot loading at **~2.8 Hz** ([measured](https://www.ncbi.nlm.nih.gov/pmc/articles/PMC12819309/))
that no step-counter counts — and at that rate, a few hours a day is **tens of thousands
of forefoot cycles, often more than a full day of walking steps.**

the hidden forefoot dose

`bounce.py` detects the bounce (FFT), counts the cycles, and integrates the **forefoot
pressure-time (dose)** — the cumulative load that peak pressure misses. Demo: **40,320
cycles/day ≈ 5.8× a typical 7,000 steps.**
```bash
python bounce.py --demo --hours-per-day 4
```
For a forefoot-loader this **stacks on top of gait** — the ball of the foot never rests.
But leg-bounce is a **self-regulating / stim movement** (ADHD / autism / anxiety); the
goal is to **dose** it (soft forefoot pad while seated, ball-of-foot rest windows, vary
the pattern), *not* to suppress it. Measure it so you can manage it.

Not medical advice — a screening/training aid; work with a clinician who knows your history.

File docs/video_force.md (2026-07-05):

# Video → force (and the kinetic chain)

Two ideas the sensor alone can't reach: **estimate the force even without an insole**
(from video), and **connect foot loading to injuries up the chain** (hamstring, ACL,
shin — "it's all connected to the foot").

kinetic chain

## Video → force — [`integrations/video_force.py`](../integrations/video_force.py)
2D-pose → vertical GRF is validated ([PMC11057390](https://www.ncbi.nlm.nih.gov/pmc/articles/PMC11057390/)).
Feed the athlete's **center-of-mass vertical trajectory** (from any pose estimator —
MediaPipe / OpenPose / BlazePose) and it applies the single-body model
`F(t) = m·(a_com + g)`, then **checks the peak against the cited published range** for
that sport and flags **L/R asymmetry** (an ACL precursor > 10–15%).

```bash
python video_force.py --demo                                   # CoM demo
python video_force.py --pose com_y.json --mass-kg 60 --profile jump_landing
python video_force.py --flight-time 0.42 --contact-time 0.12 --mass-kg 60 --profile jump_landing
python video_force.py --peak-left-bw 4.6 --peak-right-bw 3.7    # asymmetry only
```
> Demo: CoM landing → **6.8× BW (ABOVE the published 3–6× jump-landing range → injury-relevant)**;
> and left 4.6× vs right 3.7× → **20% asymmetry → ACL precursor**.

**Estimate, not a measurement.** When you *do* have the insole, it measures the pressure
directly; video fills in when you don't — and the DB gives the published range to check
the estimate against ("estimation fine, exact better").

## Kinetic-chain injuries — [`refs/plantar_norms.json`](../refs/README.md) `chain_rules`
A foot-loading **signature** maps to injuries **up the chain**:

| Signature | Chain injury | Seen in |
|---|---|---|
| High vGRF + loading rate (stiff landing) | **ACL** · tibial bone stress | jump / gym |
| L/R asymmetry > 10–15% | non-contact **ACL** · hamstring | soccer cut |
| Over-stride (foot lands ahead) in sprint | **HAMSTRING** (late-swing eccentric) | soccer sprint |
| Medial collapse / overpronation | shin splints (MTSS) · PF · knee valgus → ACL | runner |
| Lateral overload / supination | ankle sprain · 5th-met (Jones) · IT band | cutter |

`analysis/zone_load.py` prints the chain injury for the movement's profile, and the
over-used zones now report their **anatomical position in mm on your foot** (scaled by
`--foot-length-mm`) — e.g. *met2 ≈ (x 38, y 189) mm, the 2nd-met head*.

Sources: hamstring [PMC6188997](https://pmc.ncbi.nlm.nih.gov/articles/PMC6188997/) /
[soccer HSI review](https://www.frontiersin.org/journals/public-health/articles/10.3389/fpubh.2026.1846524/full);
ACL [PMC4920967](https://pmc.ncbi.nlm.nih.gov/articles/PMC4920967/) /
[PMC8359711](https://pmc.ncbi.nlm.nih.gov/articles/PMC8359711/). Not a medical device.

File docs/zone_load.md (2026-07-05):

# Zone load vs the field — down to the 2nd metatarsal

Rubrics get *specific*. Not just "your landing was clean," but **which foot regions
you over-use or under-use versus what the research says is normal for that movement** —
and the injury that overload predicts. [`analysis/zone_load.py`](../analysis/zone_load.py)
compares your per-zone distribution against the cited [`refs/plantar_norms.json`](../refs/README.md).

zone load vs the field

## How it works
1. The 8-FSR rig gives per-zone load; **met2 & met4 are interpolated** from neighbors
   (so we can still flag the injury-critical 2nd metatarsal).
2. Your distribution is compared to the **field's norm** for the chosen movement →
   a ratio per zone. **≥1.3× = over-used, ≤0.7× = under-used.**
3. Overload at a `watch_zone` raises the specific **injury** flag (e.g. central-met →
   stress fracture).
4. If you pass `--calibration` + `--bodyweight-kg`, it also puts your **peak force in
   body-weights** next to the published elite range.

```bash
python zone_load.py --demo --profile ballet_releve
python zone_load.py session.csv --profile running_forefoot --calibration cal.json --bodyweight-kg 62
```

## Worked demo ([report](../sample/results/report_zone_load.md))
A dancer whose load has shifted **off the hallux onto the met heads** (the published
1st-MTP-pain pattern):
> **Over-used:** met3 **1.8×**, met4 **2.2×**, met2 **1.3×** (interp). **Under-used:**
> hallux **0.2×**, toes **0.5×**. → *"central-met (2nd-met) overload is the 'dancer's
> fracture' route — cue big-toe engagement, check the 1st ray."*

Run the **same athlete** against `running_forefoot` and the flags change — because the
norm changes. That's the point: **over/under-use is relative to the field.**

## Grounded in research, honestly flagged
The norms come from sports-medicine literature (gymnastics **7.1–15.8× BW**, skating
**~5–8× BW**, running central-met dominance, ballet hallux↔met-head shift, 2nd-met as
the #1 stress-fracture site). **Every value is flagged** `published` / `published_order`
/ `estimated` — see [refs/README](../refs/README.md). "Estimation is fine; exact is
better," and the DB tightens as sources + our own captures are added.

**Now included (v0.2):** over-used zones report their **anatomical position in mm** on
your foot (`--foot-length-mm`, e.g. *met2 ≈ (38, 189) mm*), and the profile prints its
**kinetic-chain injury** — foot loading connects to **hamstring / ACL / shin**, not just
the foot (see [video_force.md](video_force.md)). **soccer** (`soccer_sprint`,
`soccer_cut`) and `jump_landing` (ACL) profiles are in.

**More demographics, same engine:** add a `profile` (martial-arts kick, tennis serve,
clinical walking) and the whole over/under-use + injury read comes for free. **Video → force** estimation (2D-pose →
GRF, [PMC11057390](https://www.ncbi.nlm.nih.gov/pmc/articles/PMC11057390/)) is a natural
connector: it *estimates* the force; this DB gives the *published* range to check it.

Not a medical device — a training/screening aid; verify against primary sources for clinical use.

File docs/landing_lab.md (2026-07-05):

# Landing lab — discipline-aware landing scores

The same landing is a different question in each sport. [`analysis/landing_lab.py`](../analysis/landing_lab.py)
detects the impact from the insole, then scores it against the **right rubric** —
because "good" means *stop* in gymnastics, *glide* in skating, and *soft* in dance.

landing lab — three rubrics

> **They all land forefoot-first** — then diverge: gymnastics plants the heel and
> *freezes*; dance *rolls* toe→ball→heel softly; skating stays on the ball and *glides*
> out on an edge.

| Discipline | Land on | "Good" = | Scored on | Demo |
|---|---|---|---|---|
| **Gymnastics** (`--discipline gymnastics`) | forefoot → heel, both feet | **stick** — stop dead | settle time · wobbles · step | **9.8 STUCK** |
| **Figure skating** (`figure_skating`) | one foot, ball, **outside edge** | clean **edge check-out** | 1-foot · edge (ML) control · forward flow · absorption | **9.7 clean edge** |
| **Dance / ballet** (`dance`) | toe → ball → heel roll | **soft & quiet** | impact softness · roll (heel-lag) · plié · control | **9.9 soft roll** |

## What it measures (shared primitives)
From the impact onward: **loading rate** (soft plié vs slam), **forefoot/heel roll**
(does the heel engage *after* the forefoot?), **edge** (medial/lateral pressure →
inside/outside edge + chatter), **forward flow** (COP progressing into a glide),
**settle/wobbles/step**. Each rubric weights these differently.

```bash
python landing_lab.py --demo                                   # one clean rep per discipline
python landing_lab.py "session.csv" --discipline figure_skating --calibration cal.json
```
Worked report: [sample/results/report_landing_lab.md](../sample/results/report_landing_lab.md).

## More demographics, same engine
This is the pattern for going beyond foot pain: the **COP + load** engine is
sport-agnostic; each population just needs its own rubric.
- **Volleyball / basketball** — jump-landing knee-safety (loading rate, symmetry) for ACL risk.
- **Running** — footstrike (heel vs mid vs fore), loading rate, pronation over a run.
- **Martial arts / boxing** — stance stability, weight shift, kick base.
- **Older adults** — the [clinical + mCTSIB](balance_positions.md) side.
Add a scorer, reuse the primitives.

Not a medical device — a training / performance aid. Work with your coach; sync each rep
to your existing video by timestamp — the sensor adds the pressure layer the camera can't see.

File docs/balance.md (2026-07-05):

# Balance module — posturography from the same rig

**The extrapolation:** the same insole hardware (FSR center-of-pressure + IMU) is also a **wearable balance lab**. For people with **balance issues** — not just foot pain — `analysis/balance.py` turns a standing recording into standard **posturography** metrics + fall-risk flags. Same sensors, same pod, new capability.

Balance module detail

> 🧭 **More stances?** [**balance_positions.md**](balance_positions.md) runs the full clinical battery — **mCTSIB** (firm/foam × eyes open/closed → vision/somatosensory/**vestibular** reliance), **single-leg L vs R** asymmetry, **tandem**, and **Limits of Stability** — with `analysis/balance_positions.py`.
>
> 🔌 **Devices?** [**balance_assist.md**](balance_assist.md) closes the loop with **Apple Watch** (Walking Steadiness cross-ref), **Parkinson's cueing glasses** (freezing-of-gait → floor-lines/metronome), and **smart walkers** (foot+handle load → adaptive brake). Code in [`integrations/`](../integrations/README.md).
>
> 🤸 **Athletes?** [**beam_balance.md**](beam_balance.md) is the specialized case — gymnasts on the beam: mediolateral control + a judge-style **landing "stick"** score (`analysis/beam_balance.py`).

## Who it's for
Anyone screening or training **postural stability**: older adults (fall risk), vestibular / proprioceptive issues, neurological conditions, hypermobility, post-injury return-to-play. **Not a diagnosis** — a screening/training aid to use with a clinician.

## Protocols (label the runs)
Long-press the pod button to name each condition (it becomes the `mode` column):
- **`eyes_open`** — quiet standing, 30 s, feet together.
- **`eyes_closed`** — same, eyes shut (isolates vision → the Romberg test).
- **`single_leg`** — one-leg stance (harder; stability/time).
- Optional: firm vs foam surface, dual-task (counting), etc.

## Metrics (standard posturography)
| Metric | What it is | Higher = |
|---|---|---|
| **Sway ellipse area** (mm²) | 95% confidence ellipse of COP | more instability |
| **Path length / velocity** | how far/fast the COP travels | more correction effort |
| **ML vs AP RMS** | side-to-side vs front-back sway | direction of instability |
| **Trunk sway** (IMU) | upper-body wobble | more instability |
| **Romberg quotient** | eyes-closed area / eyes-open area | **>2 → strong vision reliance** |

## What it tells you (transparent rules)
- **Large ellipse area / high velocity** → reduced stability → fall-risk screen warranted.
- **ML-dominant** → side-to-side instability → wider base / lateral support.
- **AP-dominant** → front-back → ankle strategy / heel-toe support.
- **Romberg > 2** → leans heavily on vision (proprioceptive/vestibular deficit pattern) → balance training with eyes closed.

## Run it
```powershell
python analysis/balance.py "stand_*.csv" --out results/           # relative units
python analysis/balance.py "stand_*.csv" --calibration calibration.json --out results/
```
→ `results/report_balance.md` (findings + flags) + `balance_metrics.json`.

## Where it goes next (the assist tie-in)
Balance findings map to **device classes** the same way pressure maps to insole tweaks — e.g. ML instability → a wider/lateral-support base; strong vision reliance → a haptic/cue trainer. (This mirrors the `bml assist` "analysis → device" layer in the sibling **biomech-lab** platform.) A natural expansion, same hardware.

## Honest limits
Sway thresholds here are **relative screening** values — calibrate to the individual (baseline them) before reading absolutes. FSR COP is coarser than a lab force plate but tracks the *same* trends and is wearable + cheap.

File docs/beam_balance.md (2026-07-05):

# Beam / athlete balance (specialized)

Clinical balance asks *"are you safe?"*. Elite balance asks *"how clean was that?"*.
On a **10 cm beam**, **mediolateral (side-to-side) sway is what makes you fall off**,
and the signature score is the **landing "stick"** — judges deduct for wobbles and
steps. [`analysis/beam_balance.py`](../analysis/beam_balance.py) scores exactly that,
from the same insole COP + IMU.

beam / athlete balance

## What it scores
| | From | Metric |
|---|---|---|
| **Static hold** (scale / relevé / arabesque) | COP | **ML sway** (mm) + grade, area, velocity, hold time |
| **Landing stick** | force + COP | detect impact → **settle time**, post-landing sway, **wobble count**, **step** detection → a **0–10 stick score** |
| **Relevé load** | FSR | forefoot vs heel share (beam lives on the ball of the foot) |
| **Vision independence** | eyes-open/closed | **athlete Romberg** — here a *low* eyes-closed sway is elite (they spot; inverse of the clinical read) |

## The stick score
Detect the landing impact (steepest force onset), then over the next ~3 s:
- **settle time** = time until COP speed stays < 25 mm/s,
- **wobbles** = COP-speed corrections,
- **step** = a big ML shift or a re-unweight (hop),
- deductions in judge points (wobble ~0.1, step ~0.5) → `stick = 10 − deductions`.

**Worked demo** ([report](../sample/results/report_beam_balance.md)):
```bash
python beam_balance.py --demo --out sample/results
```
> `landing_clean` → **stick 10.0/10 (STUCK)** — settles at once, 0 wobbles.
> `landing_wobble` → **9.2/10** — 0.94 s settle, 2 wobbles, a step.
> `releve_hold` → **ML sway 0.42 mm (elite)**, 92 % forefoot (on the ball).

Label each element in the log (`releve_hold`, `landing_1`, `landing_2`, …); the module
picks the right analysis per label.

## Why this fits the strategy
This is the **niche**: we own the **foot-pressure + center-of-pressure** layer a
coach's camera can't see — objective ML control and stick quality, per rep. **Sync each
landing to your existing video review by timestamp** (and to any wearable you already
train with) so the sensor *adds* to the tools you have rather than replacing them.

Not a medical device — a training/performance aid; work with your coach.

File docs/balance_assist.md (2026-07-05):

# Balance-assist ecosystem — Apple Watch, Parkinson's cue glasses, smart walkers

The balance module doesn't have to stand alone. These three [`integrations/`](../integrations/README.md)
close the loop with devices people already use — **sense** with more inputs, **assist**
with real-time cues.

balance-assist ecosystem

## 1 · Parkinson's cueing glasses — [`gait_cue.py`](../integrations/gait_cue.py)
Freezing of gait ("feet glued to the floor") is a top fall cause in Parkinson's, and
the evidence-based fix is an **external cue**: **visual floor-lines** (the AR/laser
"lines" you step over), an **auditory metronome**, or a **haptic** buzz.

The module detects freezes from the ankle IMU with the classic **Freeze Index**
(freeze-band 3–8 Hz power ÷ locomotor-band 0.5–3 Hz power) and emits a **cue-event
stream** a paired device plays. Worked demo: **2 freezes → 10 cue events** (lines on +
metronome @110 bpm + buzz at each freeze, off on resume).
```bash
python integrations/gait_cue.py --demo --out sample/results
```

## 2 · Apple Watch — [`apple_watch.py`](../integrations/apple_watch.py)
Apple Watch + iPhone already compute **Walking Steadiness** (a validated fall-risk
score) plus walking asymmetry, double-support, speed, and step length. The adapter
reads an **Apple Health export** and **cross-references** the insole — two independent
systems corroborating each other. Worked demo:
> Apple **Steadiness Low (42%)** + insole **mCTSIB vestibular ×7.9** → independent
> fall-risk agreement; Apple asymmetry 14% + insole single-leg **51% (left)** → both
> flag the same side.
```bash
python integrations/apple_watch.py sample/apple_health_export_sample.xml \
    --balance sample/results/balance_positions.json --out sample/results
```

## 3 · Smart walker / rollator — [`walker.py`](../integrations/walker.py)
A sensorized walker measures load through the **handles**; the insole measures load
through the **feet**. Together → **% weight through the walker** (a rehab-progress
number that should fall over time), left/right lean, and a **grab detector** (a spike
onto the handles + drop of foot load = a near-fall) that fires an **adaptive-brake +
alert** command a robotic walker consumes. Worked demo: **16% weight through the
walker, 3 grabs → 3 brake+alert commands.**
```bash
python integrations/walker.py --demo --out sample/results
```

## What's real, what needs the device
Each module implements the **algorithm + the data contract** (cue-event / telemetry
JSON — schemas in [integrations/README](../integrations/README.md)). The final hop is a
thin transport the target hardware defines: **BLE/serial** to cue glasses, laser-shoes,
or a robotic walker; a small **HealthKit companion iOS app** for live Watch streaming.

Freezing-of-gait cueing and walker braking are **assistive prototypes — not a medical
device.** Pair with neurology / PT / audiology.

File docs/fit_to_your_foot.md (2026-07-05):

# Fitting the insole to *your* foot

Two things make an insole yours: **where it offloads** (from your measured pressure)
and **the shape it wraps** (your foot's outline + arch). The pressure side is already
personal — `interpret.py` places the relief window, posting, and cushion from *your*
data. This page is about the **geometry**.

`hardware/build_insole.py` offers three fit levels — same directives, better fit:

| Level | Command flag | Fit | Needs |
|---|---|---|---|
| 1 · Generic | *(default)* | a nominal footbed | nothing |
| 2 · Measurements | `--length --forefoot-width --heel-width --arch-height` | scaled to your foot's size + arch | a ruler |
| 3 · Scan | `--scan your_orthotic.stl` | your **real** outline + arch contour | a phone scan |

All three carve the relief window at the **same data-driven hot spot** — they differ
only in the body they carve it into.

---

## Level 2 — fit by measurements (a ruler, 2 minutes)
Measure your foot (stand on paper, trace, measure; barefoot, weight-bearing):

- **length** — heel to longest toe (mm)
- **forefoot width** — widest part, across the ball
- **heel width** — across the heel
- **arch height** — gap under the arch at its highest (0 = flat; ~10–18 mm typical)

```bash
python build_insole.py --spec ../sample/results/insole_spec.json \
  --length 262 --forefoot-width 99 --heel-width 64 --arch-height 14 --side right
```

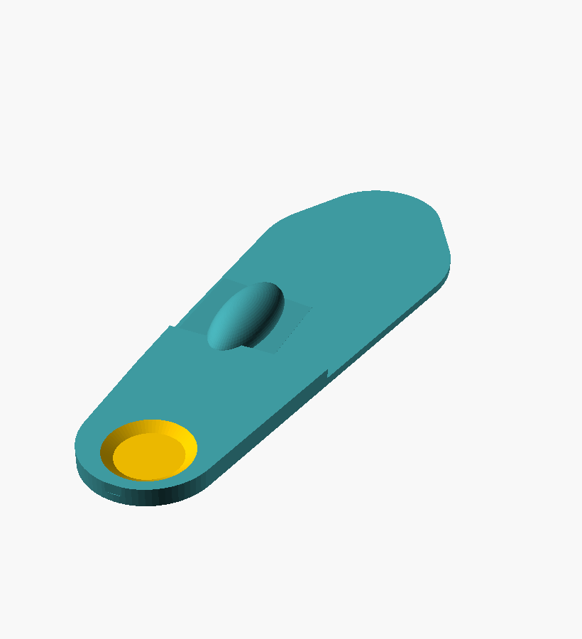
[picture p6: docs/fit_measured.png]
measurement-fit insole


*The footbed scales to your dimensions and grows a medial arch dome; the relief pocket,
medial post, and heel cushion are placed from your pressure data.* Use `--side left` for
the left foot.

---
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

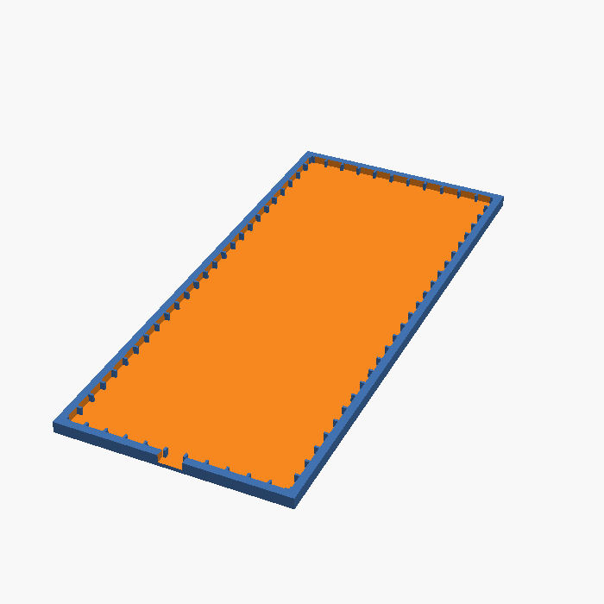
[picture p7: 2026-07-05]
hardware/pressure_mat.png

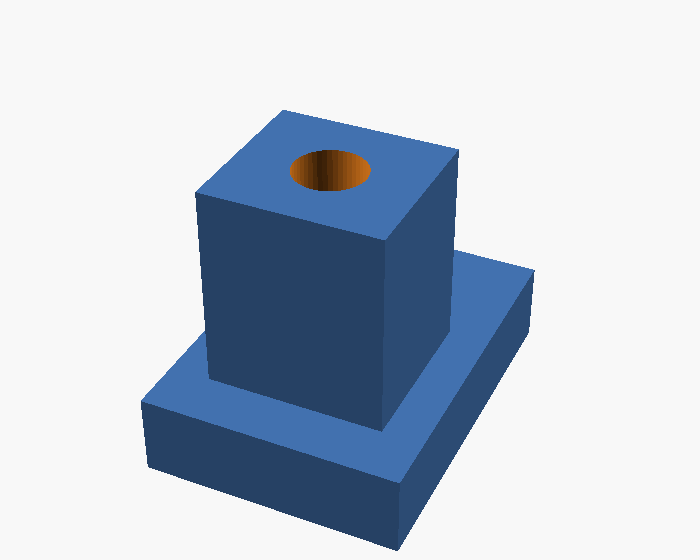
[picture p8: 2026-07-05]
hardware/force_plate.png

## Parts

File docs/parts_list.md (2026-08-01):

# Ready-to-order parts — WITHOUT printer vs WITH printer (kept separate)

Both paths share the same **electronics rig** (you need the sensors either way). What differs is how you make the mounts and the **final insole**. Buy the **Core rig**, then add **only** your path's extras.

---

## 🔩 Core rig — buy for EITHER path (~$90–110)
| # | Part | Qty | ~$ | Buy | Notes |
|---|---|---|---|---|---|
| 1 | **ESP32-S3-DevKitC-1** (N8R8) | 1 | 12 | [Amazon B09MHP42LY](https://www.amazon.com/Espressif-ESP32-S3-DevKitC-1-N8R8-Development-Board/dp/B09MHP42LY) | The brain. |
| 2 | **FSR** force sensors | **8** | ~6 ea | [Adafruit #166](https://www.adafruit.com/product/166) · [Amazon multipack](https://www.amazon.com/s?k=Interlink+FSR402+force+sensitive+resistor) | ⚠️ need **8**. |
| 3 | **CD74HC4067** 16-ch mux | 1 | 2 | [Amazon B07Z45MYP3](https://www.amazon.com/CD74HC4067-16-Channel-Multiplexer-Breakout-Microcontroller/dp/B07Z45MYP3) | 8 FSRs → 1 ADC pin. |
| 4 | **BNO085** 9-DOF IMU | 1 | 20 | [Adafruit #4754](https://www.adafruit.com/product/4754) | Pronation + strike timing. |
| 5 | **microSD SPI module** + card | 1 | 8 | [Amazon module](https://www.amazon.com/s?k=micro+sd+card+module+SPI+arduino) · [card](https://www.amazon.com/s?k=sandisk+microsd+32gb) | Onboard logging. **SanDisk 32 GB card ✅ owned 2026-08-01** (order 113-4911799); the SPI breakout module is still to buy. |
| 6 | **10 kΩ resistors** | 8 | ~7 | [Amazon kit](https://www.amazon.com/s?k=10k+ohm+resistor+1%2F4w+assortment) | FSR dividers. |
| 7 | **LiPo 500 mAh** (JST-PH) | 1 | 8 | [Adafruit #1578](https://www.adafruit.com/product/1578) | Wearable power. |
| 8 | **TP4056** USB-C charger | 1 | ~6 | [Amazon](https://www.amazon.com/s?k=TP4056+usb+c+charging+module+protection) | Get the **protected** (DW01) version. |
| 9 | **Jumper wires + perfboard** | 1 | 10 | [Amazon](https://www.amazon.com/s?k=dupont+jumper+wires+kit) | Wiring + protoboard. |

**Core subtotal: ~$90–110.**

---

## 🅰️ WITHOUT a printer — add these (improvise + print service)
| Part | ~$ | Buy | Notes |
|---|---|---|---|
| **EVA foam 3–4 mm** or cheap insoles | 8 | [Amazon EVA](https://www.amazon.com/s?k=eva+foam+sheet+3mm+adhesive) · [insoles](https://www.amazon.com/s?k=cheap+foam+shoe+insoles) | Mount the 8 FSRs on this. |
| **Double-sided tape + small project box** | 8 | [tape](https://www.amazon.com/s?k=double+sided+mounting+tape) · [box](https://www.amazon.com/s?k=small+project+enclosure+box) | Sensor cover + electronics enclosure. |
| **Final insole** | per-print | — | Send your STL to a **TPU print service** (⚠️ confirm *flexible* TPU) or a local maker. |

**Path A total: ~$105–125** + a per-insole print-service fee. **No big purchase.**

---

## 🅱️ WITH a printer (Bambu H2D) — add these
*(Skip the EVA/tape/box — you print the sensor-carrier + enclosure instead.)*
| Part | ~$ | Buy | Notes |
|---|---|---|---|
| **Bambu Lab H2D** | 1,699 | [Bambu store](https://us.store.bambulab.com/products/h2d) | Dual nozzle → soft + firm in one print. Sale ends Jul 15. |
| **H2D TPU High-Flow Kit** | 34 | [Bambu store](https://us.store.bambulab.com/products/h2d-tpu-high-flow-kit) | Footwear-tuned TPU hotends. |
| **Firm TPU — Bambu TPU 95A HF** | ~30 | [Bambu store](https://us.store.bambulab.com/products/tpu-95a-hf) | Support shell. |
| **Soft cushion TPU — Bambu TPU 85A** | ~34 | [Bambu store](https://us.store.bambulab.com/products/tpu-85a-tpu-90a) | The squishy heel layer (won't bottom out). Alt: [ColorFabb VarioShore](https://www.amazon.com/s?k=colorfabb+varioshore+tpu) (foaming, Amazon). |
| **PLA Basic / PETG** | ~25 | [PLA](https://us.store.bambulab.com/products/pla-basic-filament) · [PETG](https://us.store.bambulab.com/collections/petg) | Enclosure + Cheeq molds. |

**Path B total: Core (~$100) + ~$1,830 printer & materials.**

---

## Which path?
- **Just measuring, or a one-off insole** → **Path A** (cheapest start; outsource the print).
- **Want to iterate the insole + reuse the printer** (Cheeq molds, enclosures, everything else) → **Path B**.

You can always **start with Path A** to find your hot spot, then move to Path B only if you decide to fabricate/iterate yourself.

---

## 🧴 CHEEQ — separate private venture (not the foot lab)
> Cheeq is a **separate, private** project tracked in its own repo. Its materials/specs are **kept out of this public repo** (patent-pending). Not part of — and not needed for — the foot build.

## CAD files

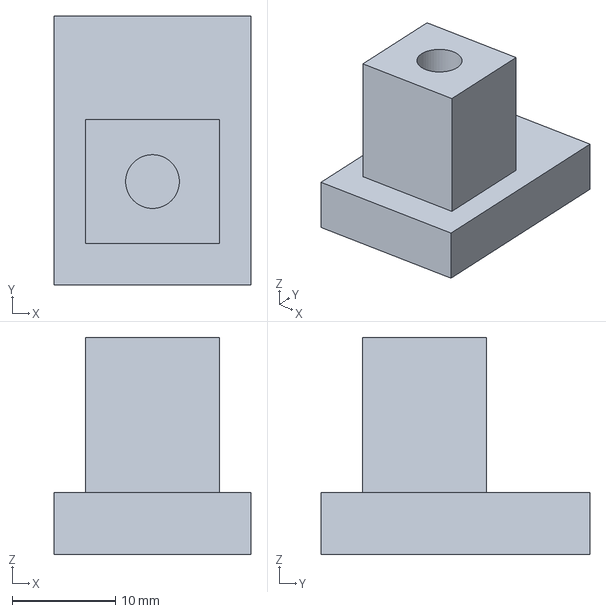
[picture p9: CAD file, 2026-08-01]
hardware/print/force_plate.3mf
19.0 x 26.0 x 21.0 mm

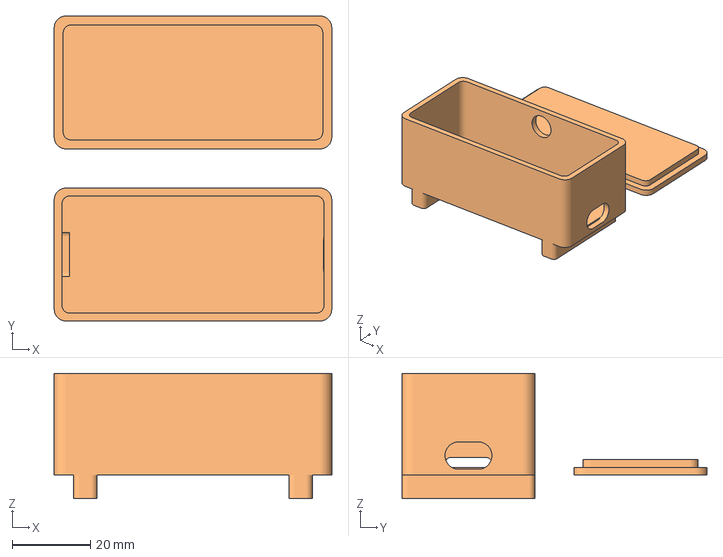
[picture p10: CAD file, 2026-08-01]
hardware/print/ankle_pod.3mf
71.0 x 78.0 x 32.0 mm

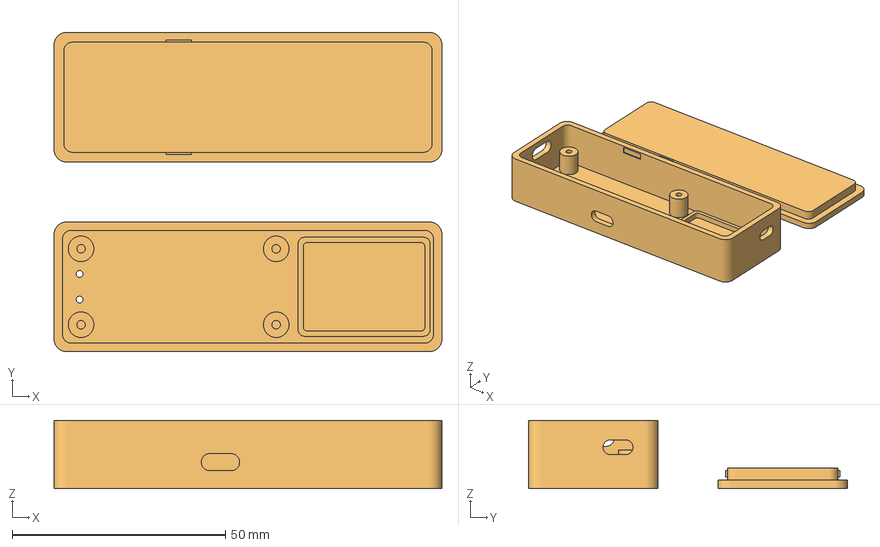
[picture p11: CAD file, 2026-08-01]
hardware/print/ankle_pod_enclosure.3mf
90.9 x 74.8 x 16.0 mm

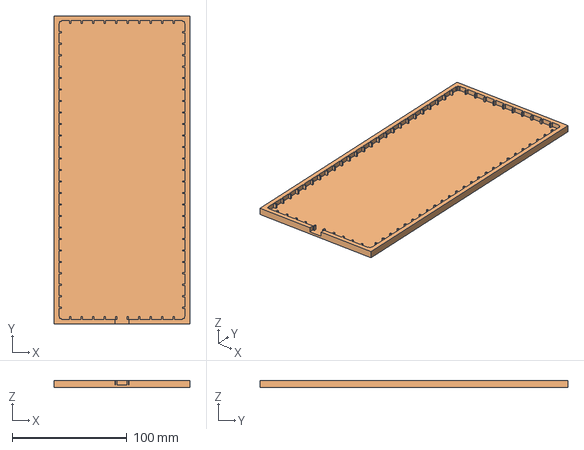
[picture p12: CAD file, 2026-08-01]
hardware/print/pressure_mat.3mf
118.0 x 268.0 x 6.00 mm

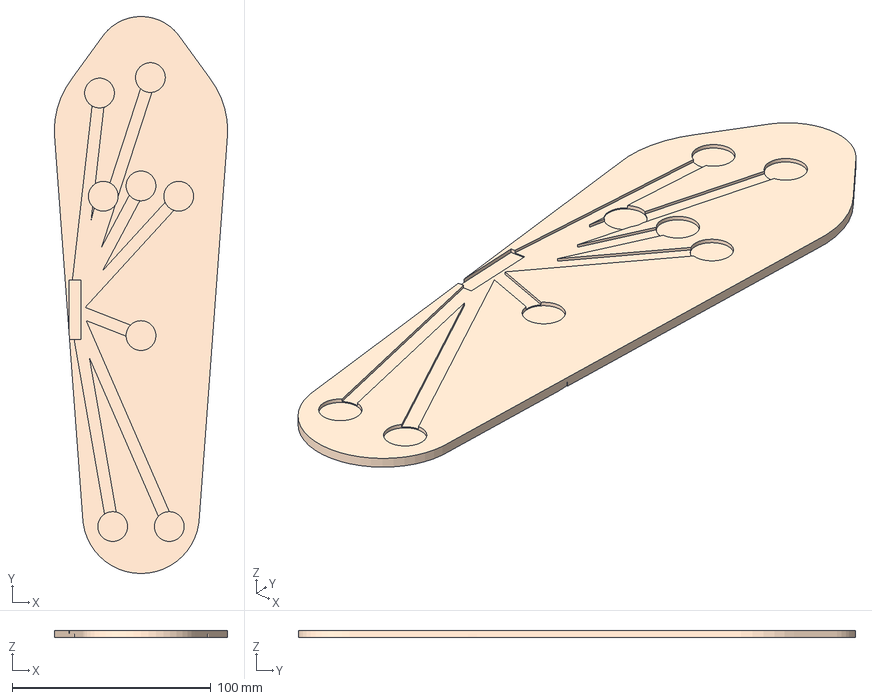
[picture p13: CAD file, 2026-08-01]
hardware/print/barefoot_sole.3mf
87.4 x 280.6 x 3.50 mm

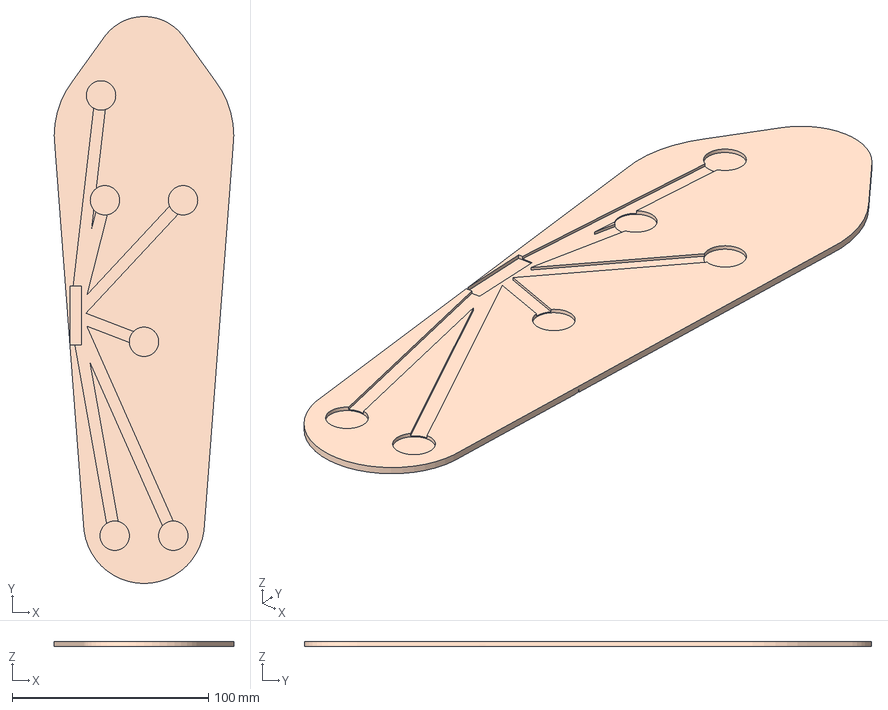
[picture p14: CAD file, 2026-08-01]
hardware/print/insole_fsr_layout.3mf
91.5 x 288.9 x 2.50 mm

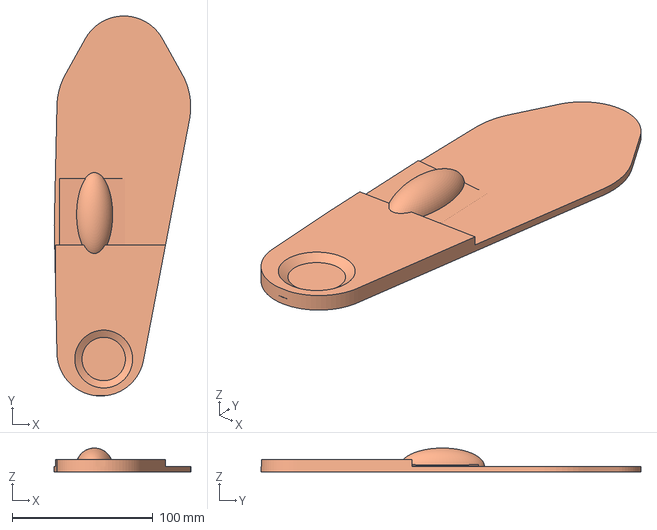
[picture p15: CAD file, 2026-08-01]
hardware/print/relief_insole.3mf
96.9 x 269.7 x 17.0 mm

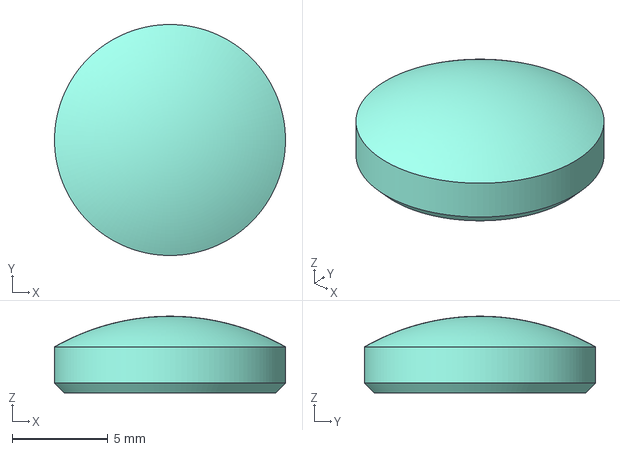
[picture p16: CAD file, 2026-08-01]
hardware/print/fsr_puck.3mf
12.1 x 12.1 x 4.00 mm

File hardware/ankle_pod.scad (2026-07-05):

// ankle_pod.scad — parametric enclosure for the Path 2 tracking pod
// Holds ESP32-S3 DevKitC + LiPo + microSD module; clips to ankle/laces.
// Usage: open in OpenSCAD -> F6 -> Export as STL. Print in PLA or PETG.
// ⚠️ MEASURE your actual boards + battery and edit the parameters below.
// All units mm.

/* ---------- parameters (edit to your parts) ---------- */
wall     = 2.0;
inner_l  = 67;    // interior length  (ESP32-S3 board + a little slack)
inner_w  = 30;    // interior width
inner_h  = 24;    // interior height  (board stacked over the LiPo)
rad      = 3;     // outer corner radius
usb_w    = 12;    // USB-C opening width  (for charging + flashing)
usb_h    = 7;     // USB-C opening height
btn_d    = 8;     // button hole diameter
ribbon_w = 12;    // sensor-ribbon slot width
ribbon_h = 3;     // sensor-ribbon slot height
strap_w  = 24;    // ankle strap width it must pass
$fn      = 48;

out_l = inner_l + 2*wall;
out_w = inner_w + 2*wall;
out_h = inner_h + wall;          // open-top shell; lid is separate

/* ---------- helpers ---------- */
module rbox(l, w, h, r){         // rounded box, centered in X/Y, base at z=0
  hull() for (x = [-1,1], y = [-1,1])
    translate([x*(l/2 - r), y*(w/2 - r), 0]) cylinder(r = r, h = h);
}

/* ---------- the pod (shell) ---------- */
module pod(){
  difference(){
    rbox(out_l, out_w, out_h, rad);
    // interior cavity
    translate([0, 0, wall]) rbox(inner_l, inner_w, inner_h + 1, max(rad - 1, 1));
    // USB-C cutout on the +X end
    translate([out_l/2 - wall - 0.1, 0, wall + 3]) rotate([0, 90, 0])
      hull() for (y = [-1,1]) translate([0, y*(usb_w/2 - usb_h/2), 0]) cylinder(d = usb_h, h = wall + 2);
    // button hole on the +Y side (near the top)
    translate([0, out_w/2 - wall - 0.1, wall + inner_h - 6]) rotate([-90, 0, 0]) cylinder(d = btn_d, h = wall + 2);
    // sensor-ribbon slot on the -X end, near the floor
    translate([-out_l/2 - 0.1, 0, wall + 1]) rotate([0, 90, 0])
      hull() for (y = [-1,1]) translate([0, y*(ribbon_w/2 - ribbon_h/2), 0]) cylinder(d = ribbon_h, h = wall + 2);
  }
  // two strap slots under the base to thread an ankle strap
  for (sx = [-1, 1]) translate([sx*(out_l/2 - 8), 0, 0]) difference(){
    translate([0, 0, -6]) rbox(6, out_w, 6, 1.5);
    translate([0, 0, -7]) cube([3, strap_w, 8], center = true);
  }
}

/* ---------- press-fit lid (printed beside the pod) ---------- */
module lid(){
  translate([0, out_w + 10, 0]){
    rbox(out_l, out_w, wall, rad);
    translate([0, 0, wall]) rbox(inner_l - 0.6, inner_w - 0.6, 2, max(rad - 1, 1));  // lip
  }
}

pod();
lid();

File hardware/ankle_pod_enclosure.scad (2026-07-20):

// ankle_pod_enclosure.scad — parametric 2-part enclosure for the STEMMA-QT ankle pod
// (ESP32-C6 Feather + flat-pouch LiPo underneath it + MPU-6050, strapped to the lower shin/ankle)
//
// This is the STEMMA-QT / Feather revision of the Path 2 electronics — see docs/BUILD_PLAN.md.
// It's a SEPARATE part from hardware/ankle_pod.scad, which holds the older ESP32-S3 DevKitC +
// CD74HC4067 mux + BNO085 rig documented in the main README. Both designs are kept in the repo;
// use whichever matches the BOM you actually bought.
//
// Usage: open in OpenSCAD -> F6 (render) -> Export as STL. base() and lid() print side by side.
// Print in PETG or PLA-CF (stiffer, but more brittle at the snap ribs — PETG is the safer bet
// if you'll open the lid often). Skip TPU for the shell itself; if you want the pod to hug a
// curved shin instead of being lashed flat, print the STRAP itself in TPU (flexible, no sewing)
// and thread it through the slots below — see strap_keeper() at the bottom.
//
// ⚠️ MEASURE your actual Feather, LiPo, and MPU-6050 breakout and correct the numbers below —
// especially feather_hole_dx/dy (this is the standard Adafruit Feather 2.0"x0.9" spacing, but
// confirm against your board) and the MPU-6050 footprint (many small STEMMA QT breakouts have
// NO standardized mounting holes, which is why it's zip-tied into a lip pocket here rather than
// screwed down).
//
// All units mm.

/* ================= PARAMETERS ================= */

// -- fit --
wall = 2.0;       // shell wall thickness
tol  = 0.3;       // clearance around components / lid friction-fit allowance per side
$fn  = 64;

// -- ESP32-C6 Feather (Adafruit #5933, STEMMA QT) --
feather_l       = 50.8;   // board length, long axis — USB-C sits on the short +X end
feather_w       = 22.8;   // board width
feather_hole_dx = 45.72;  // 1.8" — Adafruit Feather-standard mounting-hole spacing, long axis
feather_hole_dy = 17.78;  // 0.7" — Feather-standard mounting-hole spacing, short axis
feather_hole_d  = 2.5;    // Feather mounting-hole diameter
board_clear_h   = 7;      // clearance above the board TOP for the USB-C plug + STEMMA QT
                           // header + any solder — the lid's inner ceiling sits this high above it

// -- LiPo flat pouch cell (rides UNDER the Feather, stacked) --
// ⚠️ FORM FACTOR IS A DESIGN CONSTRAINT, NOT A PREFERENCE. This pod is body-worn, and variants
// of it ride the shin, the foot, inside a shoe, or on an AFO. It MUST be a flat pouch cell.
// A cylindrical 18650 (18 mm dia x 65 mm) will NOT work here — it's a rigid tube that cannot
// sit under a board or against a limb. Keep an 18650 for the STATIONARY builds only
// (bed mat / force-plate electronics), never for anything worn.
//
// Runtime is NOT the binding constraint — the pod records sessions (gait passes, stance trials),
// not 24/7 — so trade capacity for thinness every time.
//
// Adafruit flat-pouch options (all ship with JST-PH 2-pin + protection circuit):
//   500 mAh  -> 30 x 19 x 6    ~5 h   thinnest; use for in-shoe / under-AFO
//   1200 mAh -> 35 x 20 x 6    ~10 h  DEFAULT — best thinness/runtime balance
//   2000 mAh -> 60 x 36 x 7    ~18 h  long; shin-pod only
//   2500 mAh -> 50 x 34 x 10   ~22 h  too thick for shoe/AFO use
//
// NOTE: at 20 mm wide the cell is NARROWER than the Feather (22.8 mm), so the FEATHER now sets
// the case width — the shell gets ~12 mm slimmer than the old 2500 mAh build, and standoff_h
// drops from 11 mm to 7 mm. That slimming is the whole point of the change.
lipo_l   = 35;              // 1200 mAh flat pouch
lipo_w   = 20;
lipo_h   = 6;
lipo_gap = 1;               // clearance between the LiPo top and the Feather standoffs

// -- IMU STEMMA QT breakout — mounted in its own end bay, floor-level --
// ⚠️ SIZED FOR THE LARGER BOARD ON PURPOSE. Two IMUs are in play:
//     MPU-6050 (6-DoF, on hand)      ~18.0 x 13.0 mm   I2C 0x68
//     BNO085   (9-DoF, incoming x3)  ~25.5 x 17.8 mm   I2C 0x4A   <-- bigger AND different address
// The BNO085 is the intended upgrade (on-chip fusion, outputs a quaternion directly instead of
// needing host-side Madgwick). A pocket cut for the MPU-6050 will NOT accept it, so the bay is
// sized for the BNO085. Retention here is a lip + zip-tie, not an interference fit, so the
// smaller MPU-6050 still sits fine in the larger pocket — shim it or just let the tie hold it.
// Drop these back to 18/13 only if you have committed to the MPU-6050 permanently.
imu_l          = 25.5;
imu_w          = 17.8;
imu_pocket_pad = 1.5;       // clearance around the board inside its retaining lip
imu_lip_h      = 1.8;       // retaining-lip wall height (straight extrusion — zero overhang)
imu_zip_w      = 3;         // zip-tie slot width — belt-and-suspenders retention, since most
                             // small IMU breakouts have no trustworthy screw-hole pattern

// -- connectors / cutouts --
usb_w    = 10;   usb_h    = 4.2;  // USB-C opening — charge + flash without opening the case
stemma_w = 7;    stemma_h = 3.5;  // STEMMA QT cable exit — continues the I2C chain out to the
                                    // externally-worn VCNL4200 (see docs/BUILD_PLAN.md)
sensor_w = 9;    sensor_h = 4;     // FSR lead-bundle / JST exit toward the insole
drain_d  = 1.6;                    // USB-end drain holes — this pod rides the shin, exposed to
                                    // sweat/rain; lets moisture that gets in run back out

// -- strap --
strap_w    = 25;   // ~25 mm elastic, per the project brief
strap_boss = 7;     // boss length along X (each strap-slot pillar)

// -- lid snap feature (base's groove + lid's rib, see base()/lid()) --
snap_engage  = 0.2;    // rib interference against the wall DURING insertion travel — small
                        // and safe for PETG/PLA-CF, not a big structural flex
snap_relief  = 0.35;   // groove relief depth, cut into the wall — deliberately deeper than
                        // snap_engage so the rib has slack once fully seated (the "click")
snap_depth   = 1.5;    // how far below the cavity's top opening the snap band sits
snap_len     = 6;      // rib/groove length along X
snap_h       = 1.6;    // rib/groove height along Z

/* ================= DERIVED ================= */
main_inner_l = max(feather_l, lipo_l) + 2*tol + 3;   // Feather+LiPo bay footprint
main_inner_w = max(feather_w, lipo_w) + 2*tol + 3;   // FEATHER (22.8 mm) governs this now — the 20 mm cell is narrower
standoff_h   = lipo_h + lipo_gap;                     // Feather standoff height off the floor
inner_h      = standoff_h + board_clear_h;            // shared by the whole case — simplest,
                                                        // most printable: one uniform height

imu_bay_l = imu_l + 2*imu_pocket_pad + 4;             // extra LENGTH tacked on one end for the
                                                        // IMU — its 13 mm width fits easily
                                                        // inside the Feather-driven case width, so
                                                        // no extra width is needed, only length

inner_l = main_inner_l + imu_bay_l;
inner_w = main_inner_w;

out_l = inner_l + 2*wall;
out_w = inner_w + 2*wall;
out_h = inner_h + wall;     // open-top shell; lid is separate
rad   = 3;

// X layout (case centered at the origin in X/Y):
//   [-out_l/2] USB-C end -- Feather+LiPo bay -- IMU end bay -- [+out_l/2] STEMMA/FSR end
main_x0 = -inner_l/2;                 // start of the Feather+LiPo bay (at the USB end)
main_x1 = main_x0 + main_inner_l;     // end of that bay / start of the IMU bay
imu_x1  = inner_l/2;                  // end of the IMU bay (= +X inner wall)
imu_cx  = (main_x1 + imu_x1) / 2;     // IMU pocket center X

/* ================= HELPERS ================= */
// rounded box, centered in X/Y, base at z=0
module rbox(l, w, h, r){
  hull() for (x = [-1,1], y = [-1,1])
    translate([x*(l/2 - r), y*(w/2 - r), 0]) cylinder(r = r, h = h);
}

// horizontal stadium-shaped cutout through a wall (same low-overhang technique as
// hardware/ankle_pod.scad's USB/ribbon slots — small round-ended holes bridge cleanly on
// the H2D with no supports)
module wall_slot(w, h, len, axis){
  if (axis == "x") rotate([0,90,0]) hull() for (y=[-1,1]) translate([0, y*(w/2 - h/2), 0]) cylinder(d=h, h=len);
  else              rotate([90,0,0]) hull() for (x=[-1,1]) translate([x*(w/2 - h/2), 0, 0]) cylinder(d=h, h=len);
}

/* ================= BASE ================= */
module base(){
  difference(){
    rbox(out_l, out_w, out_h, rad);

    // ---- one continuous interior cavity: LiPo+Feather bay AND the IMU end bay ----
    // (they're one rectangle, not two — the "bay" split is just extra length at one end;
    // splitting the cut in two would only add a seam with no functional purpose)
    translate([0, 0, wall]) rbox(inner_l, inner_w, inner_h + 1, max(rad - 1, 1));
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

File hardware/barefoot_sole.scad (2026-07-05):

// barefoot_sole.scad — thin TPU footbed carrying the 8 FSRs (barefoot rig)
// Wear it strapped to a bare foot to log barefoot pressure, then compare vs
// the shoe insole. Also works as a plain shoe insole-carrier.
// Usage: open in OpenSCAD -> F6 -> Export STL. PRINT IN SOFT TPU (85A).
// For a TRUE-FIT version, boolean these pockets/channels into your SCANNED
// footbed instead of this generic outline — see docs/path2_tracking_build.md.
// All units mm.

/* ---------- parameters ---------- */
foot_len = 260;   // heel->toe footbed length (US M11 footbed ≈ 255-265)
foot_w   = 95;    // ball width
thick    = 3.5;   // footbed thickness
pocket_d = 15;    // FSR pocket diameter (pad ≈ 12.5 + slack)
pocket_h = 1.4;   // recess depth (leaves a thin membrane above the sensor)
chan_w   = 6;     // wire-channel width
$fn      = 48;

// FSR zone positions — normalized [x medial->lateral 0..1 , y heel->toe 0..1]
// (matches ZONES / SENSOR_XY in analysis/analyze_pressure.py)
zones = [ [0.35,0.08], [0.65,0.08], [0.50,0.45], [0.30,0.72],
          [0.50,0.74], [0.70,0.72], [0.28,0.92], [0.55,0.95] ];

module footbed(){
  hull(){
    translate([foot_w/2, foot_w*0.28,        0]) cylinder(d = foot_w*0.62, h = thick); // heel
    translate([foot_w/2, foot_len-foot_w*0.42,0]) cylinder(d = foot_w*0.92, h = thick); // ball
    translate([foot_w/2, foot_len-6,         0]) cylinder(d = foot_w*0.50, h = thick); // toe
  }
}

module pockets_and_channels(){
  for (z = zones){
    px = z[0]*foot_w; py = z[1]*foot_len;
    // FSR pocket (recessed from the top face)
    translate([px, py, thick - pocket_h]) cylinder(d = pocket_d, h = pocket_h + 1);
    // wire channel from each pocket toward the medial instep (x≈0.15, y≈0.5)
    hull(){
      translate([px, py, thick - 1.0]) cylinder(d = chan_w, h = 1.2);
      translate([foot_w*0.15, foot_len*0.5, thick - 1.0]) cylinder(d = chan_w, h = 1.2);
    }
  }
  // ribbon exit channel out the medial edge
  translate([foot_w*0.15 - chan_w/2, foot_len*0.5 - 15, thick - 1.4]) cube([chan_w, 30, 1.5]);
}

module strap_slots(){          // toe + ankle transverse straps
  for (y = [foot_len*0.72, foot_len*0.30])
    for (sx = [0.12, 0.88])
      translate([foot_w*sx, y, -0.5]) cube([5, 18, thick + 1], center = true);
}

difference(){
  footbed();
  pockets_and_channels();
  strap_slots();
}

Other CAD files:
hardware/force_plate.scad
docs/stemma_wiring_diagram.scad
hardware/ankle_pod.stl
hardware/ankle_pod_enclosure.stl
hardware/barefoot_sole.stl
hardware/force_plate.stl
hardware/fsr_puck.scad
hardware/fsr_puck.stl
hardware/insole_fsr_layout.scad
hardware/insole_fsr_layout.stl
hardware/pressure_mat.scad
hardware/pressure_mat.stl
hardware/relief_insole.scad
hardware/relief_insole.stl

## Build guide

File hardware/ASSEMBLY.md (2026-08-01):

# ASSEMBLY — biomech-pressure-lab hardware

One card, three sub-rigs: **relief insole**, **ankle pod** (+ FSR carrier), and **DIY-lab sensing**
(force plate, pressure mat, FSR puck). Build only the parts for the rig you're assembling. Pins below
are read straight from the committed firmware — verify against your own board revision before power.

---

## 1. After the print
- **relief_insole / barefoot_sole / insole_fsr_layout (TPU):** printed on a glue stick, no supports,
  no brim. Peel off the plate once cool; TPU releases easier warm. Pop the sensor pockets/wire
  channels clear of strings. `relief_insole` is dual-TPU (soft cushion + firm shell) — check the two
  materials fused at the interface.
- **ankle_pod / ankle_pod_enclosure (ASA):** brim used (ASA warps) — peel it off, deburr the mating
  rim flat so the lid seats. Each `.scad` prints **body + lid side-by-side on one plate** (the "2
  shells" the gate reports — expected, not a defect). No supports; USB/STEMMA/FSR slots are
  round-ended and bridge clean.
- **pressure_mat (ASA/PETG-CF):** thin comb teeth — brim on, handle gently, don't snap the teeth off.
- **force_plate (PA-CF/PETG-CF, STRUCTURAL):** dry the filament, brim recommended, 4 walls. `foot()`
  renders x4 — print four. `top_boss()` x4 and `top_plate()` are commented out in the `.scad`;
  uncomment to export if you're not using plywood/acrylic for the top.
- **fsr_puck (rigid PETG) ×6–8:** tiny solid domes, 0.12 mm layer, no supports/brim. Batch them.

## 2. Hardware & assembly
- **Ankle pod (ESP32-C6 STEMMA rig, `ankle_pod_enclosure.scad`):**
  - **Feather standoffs:** four posts drilled for **M2.5**. As-printed they're self-tap pilots
    (2.0 mm); for a lid you'll open often, drill through 2.5 mm and **press an M2.5 brass heat-set
    insert** into each, then screw the Feather down with M2.5 SHCS.
  - **IMU (MPU-6050 / BNO085):** drops into the floor-level lip pocket at the +X end — **no screws**
    (most STEMMA breakouts have no reliable hole pattern). Retain with a **zip-tie** up through one
    floor slot, over the board, down the other, cinch underneath.
  - **LiPo** (1200 mAh flat pouch, 35×20×6) sits UNDER the Feather in the main bay.
  - **Lid:** friction-fit lip + snap ribs (0.2 mm engage into a 0.35 mm groove — a click, not a
    fight). Press to seat. Optional TPU `strap_keeper()` clips into the strap slots; or thread ~25 mm
    elastic through the two under-base slots.
- **Ankle pod (older ESP32-S3 rig, `ankle_pod.scad`):** press-fit lid (0.6 mm lip clearance, no
  snap); strap through the two under-base slots; USB-C / button / sensor-ribbon slots. No inserts.
- **Force plate:** each printed `foot()` clamps the **fixed end** of a 50 kg bar load cell with an
  **M5 bolt** (`LC_hole_d=5.2`); the free end overhangs with a 2 mm air gap — **do not let it bottom
  out**. A `top_boss()` bolts to each cell's free end and presses up on the top (plywood/acrylic, or
  printed `top_plate()`); glue the bosses into the plate pockets. Rubber feet in the underside 10 mm
  pockets.
- **Pressure mat:** the printed comb is an **alignment jig** — lay copper-tape rows/cols against its
  teeth with the Velostat sheet between the two electrode layers. No fasteners; tape + frame.
- **FSR puck:** one rigid puck sits centered on each FSR's active area (funnels load the same way
  every time). It drops into the insole pocket over the sensor — no glue needed, the insole membrane
  holds it.

## 3. Wiring / electronics

### Ankle pod — 6-zone STEMMA-QT rig (ESP32-C6 Feather, `insole_fsr_layout` carrier)
6× FSR402 go straight to the Feather analog pins, **no mux**:
| Zone | FSR | Feather pin |
|---|---|---|
| heel_med | fsr0 | A0 |
| heel_lat | fsr1 | A1 |
| midfoot | fsr2 | A2 |
| met1 | fsr3 | A3 |
| met5 | fsr4 | A4 |
| hallux | fsr5 | A5 |

Each FSR = one leg to 3.3 V, other leg to its Ax pin **and** a fixed pull-down resistor to GND
(voltage divider). I2C on **SDA/SCL = STEMMA-QT bus**; MPU-6050 at **0x68**, VCNL4200 at **0x51**.
⚠️ **Firmware must drive IO20 HIGH** to power the STEMMA-QT bus or both I2C breakouts read as "not
found." Smoke-test with the lid off. Libs: Adafruit MPU6050 + VCNL4200 (+ Unified Sensor, BusIO).

### Ankle pod — 8-zone rig (ESP32-S3, `barefoot_sole` carrier, `smart_insole`/`all_day_logger`)
8× FSR402 through a **CD74HC4067 mux**:
| Signal | ESP32-S3 GPIO |
|---|---|
| MUX common SIG → ADC | GPIO1 (ADC1_CH0) |
| MUX select S0/S1/S2/S3 | GPIO2 / 3 / 4 / 5 |
| I2C SDA / SCL (BNO08x IMU) | GPIO8 / GPIO9 |
| microSD CS / MOSI / SCK / MISO | GPIO10 / 11 / 12 / 13 |
| Button / LED | GPIO14 / GPIO15 |
| VBAT sense (2:1 divider, `all_day_logger`) | GPIO16 |

`analogReadResolution(12)`, `ADC_11db` attenuation (0–~3.3 V). BNO08x IMU on I2C (0x4A default). SD
logging + BLE (Nordic UART). Run `i2c_scanner` first to confirm addresses.

### Force plate (`firmware/force_plate`, HX711)
- **Single-HX711 total-force mode (`COP_MODE 0`, default):** HX711 **DOUT = GPIO5, SCK = GPIO4**,
  one HX711 summing all four cells (or one cell). Needs the HX711 Arduino lib.
- **4-HX711 CoP upgrade (`COP_MODE 1`):** shared **SCK = GPIO4**, one data pin per corner
  **DOUT[4] = {5, 6, 7, 15}**.

### Pressure mat (`firmware/pressure_mat`, Velostat matrix, no external lib)
8 rows × 11 cols, anti-ghosting scan:
| Signal | ESP32 GPIO |
|---|---|
| ROW drive (8) | GPIO1–GPIO8 |
| MUX select S0–S3 (columns via CD74HC4067) | GPIO9 / 10 / 11 / 12 |
| MUX common SIG → ADC | GPIO13 |

Discard the first ADC read after each mux switch (settle), 30 µs settle. Render with
`analysis/mat_heatmap.py`.

**Power:** flat-pouch LiPo (JST-PH) for the worn pod; a stationary 18650 or USB is fine for the
force plate / mat. Never put an 18650 in the body-worn pod (design constraint — must be flat pouch).

## 4. Measurement / fitting — REQUIRED (custom-fit rig)

**Relief insole — needs measurement (LiDAR scan preferred, caliper fallback):**
1. **iPhone 15 Pro LiDAR scan** of your **existing orthotic (NOT a bare foot)** — matte it first
   (baby powder / matte spray), include a ruler or coin for scale. App: **Scaniverse or Polycam** →
   export **STL** → clean watertight in **Blender/Fusion**.
2. Feed it to `build_insole.py --scan my_orthotic.stl --name fitted` (best fit). It reads
   `insole_spec.json` and places the relief window / met pad / arch from your data, re-emitting
   `relief_insole.stl`.
3. **Caliper fallback (no scan):** `build_insole.py --length --forefoot-width --heel-width
   --arch-height` in mm (e.g. `--length 262 --forefoot-width 99 --heel-width 64 --arch-height 14`).
4. **Measurement inputs the model expects:** the scan STL passed to `--scan`, or the four caliper
   dims; hotspot placement comes from `analysis/` → `hotspot.json` → `insole_spec.json` (run with
   `--demo` on the committed sample if you have no sensor data yet). Full how-to:
   `../docs/fit_to_your_foot.md`.

**FSR carrier (`insole_fsr_layout`):** set `FOOT_LEN` (mm) to your measured heel→toe length; width
derives from it. Caliper or the scan gives `FOOT_LEN`.

**Ankle pod (body-worn):** caliper your **actual Feather / LiPo / MPU-6050** footprints and correct
`feather_hole_dx/dy` + the IMU pocket in `ankle_pod_enclosure.scad` before the final print (many
STEMMA breakouts vary). The pod straps to the lower shin with ~25 mm elastic — no body scan, but the
board fit **is** a caliper step.

**Force plate / pressure mat / FSR puck:** sized to spec (the load cells / Velostat / FSR402), no
body measurement.

## 5. Calibration & first-power checklist
- **Meter before power:** with the LiPo disconnected, check for shorts across 3V3↔GND. Confirm FSR
  divider pull-downs are present. For the C6 rig, verify IO20 is wired to the STEMMA power enable.
- **I2C enumerate:** flash `i2c_scanner`, lid off — confirm **MPU-6050 0x68 / VCNL4200 0x51** (C6) or
  **BNO08x 0x4A** (S3). If a device is missing on the C6, IO20 isn't HIGH.
- **FSR channels:** confirm all 6 (or 8) channels change with finger pressure before closing the lid.
- **FSR calibration:** flash `firmware/fsr_calibrate`, press **known weights** onto each puck-loaded
  zone, fit with `analysis/calibrate.py` (power-law ADC→kPa).
- **Force plate:** zero (tare) unloaded, then place a **known weight** and set the HX711 cal factor
  until reported force matches. Validated rigs hit ICC>0.94 vs a lab plate.
- **Pressure mat:** run the matrix scan empty (baseline), step on it — `mat_heatmap.py` should show a
  clean foot pressure map with no row/col ghosting.
- **"Working" looks like:** all sensors zero at rest, respond monotonically to load, IMU streams sane
  orientation, and the pod logs to SD / streams over BLE. **⚠️ Force plate is a proof-load-gated
  structural draft — proof-load it before standing full bodyweight.**

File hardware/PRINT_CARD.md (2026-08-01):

# PRINT_CARD — biomech-pressure-lab hardware

All printable STLs in this repo live in this one `hardware/` folder, so this is one card,
grouped by the three sub-projects: **the relief insole**, **the ankle pod**, and **gait /
DIY-lab sensing**. Print only the parts for the rig you're actually building (some parts are
alternative revisions — see notes).

Material choices follow the repo's intent *and* the shop policy: **PLA is prototype-only**;
functional parts use the high-grade owned stock (**PA-CF / PETG-CF / PC / ASA**); **TPU is for
soft/flex parts** (insole, sensor carriers) and always runs from the **external spool, never the
AMS**. Owned filament: plenty of TPU + the H2D AMS high-grade set (PC / ASA / PA-CF / CF).

## Ready-to-load `.3mf` (Bambu Studio)

`make_3mf.py` emits one Bambu-loadable project per STL into `print/` (single object, one
base material + extruder; re-slot per the recipe below — TPU → external spool, high-grade →
AMS). Regenerate any time with `python make_3mf.py`.

`print/relief_insole.3mf` · `barefoot_sole.3mf` · `insole_fsr_layout.3mf` ·
`ankle_pod.3mf` · `ankle_pod_enclosure.3mf` · `pressure_mat.3mf` · `force_plate.3mf` ·
`fsr_puck.3mf`

**Gate results** (`_stl_bbox.py` + `_stl_islands.py`, H2D usable 325×320×325):
all 8 fit the bed with generous slack (largest footprint = `insole_fsr_layout` 91.5×288.9,
`pressure_mat` 118×268 — both well inside 320 in Y). Island check: 6 parts = 1 shell (OK).
`ankle_pod` and `ankle_pod_enclosure` report **2 shells each — expected, not a defect**: both
`.scad`s emit `pod();lid();` / `base();lid();`, i.e. the body plus its press-fit/snap lid laid
out side-by-side on one plate (lid offset to Y≈27–61). Same material, single plate — slice as-is.

## Slice recipe

| Part (.stl) | Material | Nozzle | Layer | Walls | Infill | Supports | Brim | Plate |
|---|---|---|---|---|---|---|---|---|
| `relief_insole.stl` | **TPU dual** — soft/foaming cushion 85–90A (VarioShore) + firm shell TPU 95A HF | 0.4 (0.6 High-Flow ok for cushion) | 0.20 | 2–3 | cushion 12–18% honeycomb · shell 35–45% | No | No (glue stick to release) | **P1 — insole (H2D dual-nozzle, EXTERNAL spool for soft)** |
| `barefoot_sole.stl` | **soft TPU 85A** | 0.4 (or 0.6 HF) | 0.20 | 3 | ~15% gyroid | No | No (glue stick) | **P2 — TPU carriers (EXTERNAL spool)** |
| `insole_fsr_layout.stl` | **TPU** (6-zone FSR carrier) | 0.4 | 0.20–0.24 | 2–3 | ~15% gyroid | No | No | **P2 — TPU carriers (EXTERNAL spool)** |
| `ankle_pod.stl` | **ASA** (body-worn, tough; PA-CF/PETG-CF for stiffer base) | 0.4 (hardened if CF) | 0.20 | 3 | 20% | No | Yes (ASA warps) | **P3 — ankle pod (AMS, enclosure warm)** |
| `ankle_pod_enclosure.stl` | **ASA** base+lid (or PA-CF base for shin-strap rigidity + ASA/PETG lid for snap flex) | 0.4 (hardened if CF) | 0.20 | 3–4 | 20–25% | No | Yes | **P3 — ankle pod (AMS, enclosure warm)** |
| `pressure_mat.stl` | **ASA** or PETG-CF (non-load electrode comb) | 0.4 (hardened if CF) | 0.20 | 3 | 15–20% | No | Yes (thin comb teeth) | **P4 — DIY-lab frames (AMS)** |
| `force_plate.stl` | **PA-CF / PETG-CF** — STRUCTURAL (bears bodyweight → 4 load cells); DRY the filament | 0.4 **hardened** | 0.20 | 4 | 40–100% (repo wants solid platform) | No | Yes (recommended) | **P5 — force plate (AMS, DRY, hardened)** |
| `fsr_puck.stl` ×6–8 | **PETG** rigid — *part says NO CF* (grinds the fine nozzle); PLA ok as proto | **0.2 stainless** (fine dome) — *fallback: 0.4 + 0.12mm layer if no 0.2 nozzle* | 0.12 | 3–4 | 100% (tiny/solid) | No | No | **P6 — pucks (fine-detail nozzle, batch all)** |

**How to slice:** open the STLs in Bambu Studio (H2D profile already set), assign each part's
material to an AMS slot — **except the TPU parts (P1/P2), which must feed from the external
spool, not the AMS** — arrange on the indicated plate, Slice, Print. Print **one** ankle-pod
revision (`ankle_pod` = older ESP32-S3/mux rig · `ankle_pod_enclosure` = current ESP32-C6
STEMMA-QT rig) and **one** FSR carrier (`barefoot_sole` = 8-zone · `insole_fsr_layout` = 6-zone)
to match your electronics. The force plate is a **structural draft — proof-load it before
standing full weight** (FEA/proof-load gated). The STLs are pre-rendered at default params; only
open the `.scad` in OpenSCAD if you want to re-parameterize (measure your board/foot) and
re-export.

## Software & measurement

**Insole (relief_insole) — measurement + regen (no electronics):**
- Phone: **iPhone LiDAR → Scaniverse or Polycam**. Scan your **existing orthotic, not a bare
  foot** — matte it first (baby powder / matte spray), include a ruler/coin for scale, export
  **STL**, clean watertight in Blender/Fusion.
- Feed it to `hardware/build_insole.py` (Python): `--scan my_orthotic.stl` (best fit), or caliper
  measurements `--length --forefoot-width --heel-width --arch-height` (mm). It places the relief
  window/met pad/arch from `insole_spec.json` and re-emits `relief_insole.stl` fitted to you.
- No PC software beyond Python + the `analysis/` pipeline (calibrate → interpret → `hotspot.json`
  → `insole_spec.json`). Runs on the committed sample with `--demo` if you have no sensor data.

**Ankle pod + FSR carriers — sensor-rig firmware/flashing:**
- **Arduino IDE** (or arduino-cli/PlatformIO) with the **esp32 board package** (Espressif, via
  Boards Manager). Board = *ESP32-S3 Dev Module* (older rig) or *Adafruit ESP32-C6 Feather*
  (STEMMA-QT rig).
- Libraries by sketch: `all_day_logger`/`smart_insole` → **Adafruit BNO08x** (IMU) + built-in
  `SD`/`SPI`/`Wire` (smart_insole also uses the ESP32 built-in `BLEDevice` stack). STEMMA-QT
  C6 rig → **Adafruit MPU6050** + **Adafruit VCNL4200** (+ their deps **Adafruit Unified
  Sensor**, **Adafruit BusIO**). `i2c_scanner` → `Wire` only (verify MPU 0x68 / VCNL 0x51).
  FSRs are analog reads — no library. The 8-zone rig also needs a **CD74HC4067 mux** (GPIO, no
  lib); the 6-zone C6 rig drops the mux (6 FSRs → A0–A5).
- **C6 STEMMA gotcha:** firmware must drive **IO20 HIGH** to power the STEMMA-QT bus or both
  I2C breakouts read as "not found." Flash + smoke-test with the lid off (confirm all FSR
  channels + both I2C devices enumerate).
- **Calibrate** each FSR: flash `firmware/fsr_calibrate`, record known weights, fit with
  `analysis/calibrate.py` (power-law ADC→kPa). Caliper-measure your actual board's hole spacing
  against the `.scad` standoff params before printing the enclosure final.

**DIY-lab sensing (force plate + pressure mat):**
- **force_plate:** 4× load cells + **HX711** ADC(s); flash `firmware/force_plate` (needs the
  **HX711** Arduino library — 1 HX711 = total vertical GRF; 4-HX711 CoP upgrade is in-sketch).
  Calibrate against known weights.
- **pressure_mat:** Velostat sheet + copper-tape electrode matrix (the printed comb aligns them);
  flash `firmware/pressure_mat` (matrix scan, anti-ghosting — no external lib); render with
  `analysis/mat_heatmap.py`.
- **fsr_puck:** no software — pure-print force-concentrator, one per FSR zone.

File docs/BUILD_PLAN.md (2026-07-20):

# BUILD_PLAN — STEMMA-QT ankle pod (ESP32-C6 Feather revision)

Stepwise build plan for the **updated Path 2 electronics**: ESP32-C6 Feather + VCNL4200 +
MPU-6050 (all STEMMA QT) + 6× FSR402, replacing the ESP32-S3/mux/BNO085 rig documented in the
main [README](../README.md) Path 2 section with a simpler, no-mux, STEMMA-chained build. Same
loop, same downstream analysis — just a different BOM. Print files:
[`hardware/ankle_pod_enclosure.scad`](../hardware/ankle_pod_enclosure.scad) (2-part shin pod) and
[`hardware/insole_fsr_layout.scad`](../hardware/insole_fsr_layout.scad) (flat FSR carrier); zone
math in [`docs/insole_sensor_layout.md`](insole_sensor_layout.md).

> ⚠️ **Assumptions, stated up front:** the ESP32-C6 Feather's exact GPIO-to-`Ax` mapping is
> inconsistently documented even by Adafruit (their own guide and pinout page disagree on a
> couple of pins) — so all firmware references below use the **symbolic pin names** (`A0`..`A5`,
> `SDA`, `SCL`) that the Arduino board variant resolves for you, never raw GPIO numbers. Also:
> neither the MPU-6050 nor VCNL4200 STEMMA QT breakouts have a confirmed, standardized
> mounting-hole pattern, so the enclosure holds the IMU with a retaining lip + zip-tie rather than
> screws (see the .scad comments). Verify both against your actual boards before printing final.

---

## (a) Print list — H2D settings

No part here needs supports — every overhang in both `.scad` files is a straight extrusion or a
small bridged slot (≤10 mm), both well inside the H2D's unsupported-bridging range.

| Part | Source | Material | Nozzle | Layer height | Supports | Infill | Rough time |
|---|---|---|---|---|---|---|---|
| Ankle pod **base** | `ankle_pod_enclosure.scad` → `base()` | PETG (or PLA-CF for extra shin-strap rigidity) | 0.4 mm hardened | 0.20 mm | No | 20–25% | ~2–2.5 h |
| Ankle pod **lid** | same file → `lid()` | same as base | 0.4 mm hardened | 0.20 mm | No | 20–25% | ~1 h |
| FSR **sensor-carrier plate** | `insole_fsr_layout.scad` | TPU (black, **external dryer spool, not AMS**) | 0.4 mm hardened | 0.20–0.24 mm | No | ~15% gyroid | ~1.5 h |
| FSR **force-concentrator pucks** ×6 | `fsr_puck.scad` (existing, one per zone) | plain PLA or PETG — **not** PLA-CF here | 0.2 mm stainless (fine detail on the small dome) | 0.12 mm | No | 100% (small/solid) | ~10 min ea, ~1 h batched |

Notes:
- **Puck nozzle choice:** the puck's revolved dome/rim profile is small enough that the 0.2 mm
  stainless nozzle gives a visibly cleaner result. If you do print pucks in **PLA-CF instead**
  (you don't need to — plain PLA/PETG is plenty rigid for a puck), swap to the **0.4 mm hardened**
  nozzle; carbon fiber will grind through the stainless one.
- **PETG vs PLA-CF for the pod:** PETG is the safer default — it takes the shin-strap flex and
  the lid's snap ribs better without cracking. PLA-CF (210–240 °C) is stiffer but more brittle at
  thin snap features; fine for the base, use PETG for the lid if you'll open it often.
- **H2D dual-nozzle option:** the H2D's two independent nozzles can, in principle, run two
  different jobs (e.g., PETG pod parts on one side, TPU carrier on the other) concurrently if your
  Bambu Studio profile supports independent-nozzle mode for the plate layout you have — worth
  checking before you rely on it. If not, just queue the four print jobs sequentially; see (d).

---

## (b) Electronics wiring

**STEMMA QT I2C chain** (JST-SH 4-pin cables, daisy-chained — order doesn't matter electrically):

```
ESP32-C6 Feather (STEMMA QT port)
   │ cable
   ▼
MPU-6050 breakout (0x68)         — lives INSIDE the ankle pod's IMU bay
   │ cable, continues out the pod's STEMMA-exit slot
   ▼
VCNL4200 breakout (0x51)         — worn OUTSIDE the pod (see placement note below)
```

No address conflict (`0x68` vs `0x51`), so this chains safely on one bus.
[Sources: MPU-6050 STEMMA QT breakout default address](https://learn.adafruit.com/mpu6050-6-dof-accelerometer-and-gyro/pinouts) ·
[VCNL4200 STEMMA QT breakout default address](https://learn.adafruit.com/adafruit-vcnl4200-long-distance-ir-proximity-and-light-sensor).

**⚠️ C6-specific gotcha:** the Feather's STEMMA QT connector shares the board's main I2C pins
(`SDA`=IO19, `SCL`=IO18), but the connector's **power** is switched through a separate pin
(IO20) that firmware must drive **HIGH** before anything on the chain will respond — otherwise
both breakouts read as "not found" even though the wiring is correct.
[Source: Adafruit ESP32-C6 Feather I2C guide](https://learn.adafruit.com/adafruit-esp32-c6-feather/i2c).

**VCNL4200 placement (your call, one reasonable option):** mounted facing down/forward — either
on the front of the ankle pod itself or clipped near the toe box — it can read **ground
clearance during the swing phase** (toe-drag / foot-drop risk), a natural complement to the
pressure + IMU data given this repo already tracks equinus/AFO-adjacent conditions. This is a
suggestion, not a spec — any STEMMA-chained placement works electrically.

**FSR wiring** — unchanged divider model from
[`docs/calibration.md`](calibration.md)/[`analysis/calibrate.py`](../analysis/calibrate.py):
`3V3 — FSR — node — 10 kΩ — GND`, node → ADC pin. With 6 zones and 6 analog pins, **no mux** —
each FSR lands directly on its own Feather pin:

| Zone | Feather pin |
|---|---|
| `heel_med` | `A0` |
| `heel_lat` | `A1` |
| `midfoot`  | `A2` |
| `met1` | `A3` |
| `met5` | `A4` |
| `hallux` | `A5` |

(Full zone coordinates: [`docs/insole_sensor_layout.md`](insole_sensor_layout.md).)

**Full pin-by-pin solder guide** (which pad gets which lead, perfboard layout, divider theory,
solder order, and pre-power multimeter checks): [`docs/WIRING.md`](WIRING.md).

**Power:** the LiPo 2500 mAh plugs directly into the Feather's onboard 2-pin JST-PH battery
connector — it lives inside the case, stacked under the board, no external wiring. Charges +
programs through the same USB-C port the pod exposes.

---

## (c) In-person assembly order & timing

Do this after both prints are done and the Micro Center parts are in hand (~45–75 min first
time through):

1. **Dry-fit** the Feather onto the base's four standoff posts — confirm the 2.5 mm holes line
   up before committing (measure your actual board against `feather_hole_dx`/`dy` first; adjust
   and reprint the base if they're off).
2. **Wire the 6 FSR dividers** — resistor + FSR leads to a small stub of perfboard or straight to
   the Feather's `A0`–`A5` pins and a shared `GND`. Do this **before** seating the board in the
   case; it's much easier on the bench. Pin-by-pin detail (which pad gets which lead, solder
   order, pre-power checks): [`docs/WIRING.md`](WIRING.md).
3. **Seat the LiPo** in the base first (floor of the main bay), then the wired Feather on top,
   screw into the standoffs (self-tap or heat-set insert — see (e)).
4. **Plug the battery** into the Feather's onboard JST-PH connector.
5. **Seat the MPU-6050** in the IMU-bay lip pocket, loop a zip tie up through one floor slot,
   over the board, down through the other, cinch from underneath.
6. **STEMMA-chain** Feather → MPU-6050 → (cable out the STEMMA-exit slot) → VCNL4200.
7. **Route the FSR lead bundle** out the sensor-exit slot toward where the insole carrier will sit.
8. **Dry-fit the lid** — press until the snap ribs click into the base's groove notches. If it's
   too tight/loose, see (e) for the `tol` reprint tweak.
9. **Thread the ~25 mm strap** through both strap-slot bosses; mount to the lower shin/ankle.
10. **Flash + smoke-test** before closing anything up for good — confirm all 6 FSR channels read
    and both I2C devices enumerate (see the gotcha in (b)) with the lid off.

---

## (d) Parallel/overnight prints vs. what needs the Micro Center trip first

**Blocking on the store trip (do this first, or at least in parallel with printing):** the FSR
402 10-pack, 10 kΩ resistors, an M2.5 screw or two (or a heat-set insert kit), and the elastic
strap material are the only items that gate final assembly — everything else (ESP32-C6 Feather,
LiPo, VCNL4200/MPU-6050 STEMMA breakouts, STEMMA QT cables) is presumably already inbound per the
shared BOM.

**Prints — no supports, so all four can run unattended overnight,** in whatever order fits your
plate/bed-clearing schedule:
1. Ankle pod base + lid (PETG/PLA-CF) — can share a plate.
2. FSR carrier plate (TPU, external spool) — run separately if the AMS/dryer feed setup doesn't
   like sharing a plate with the PETG job; check nozzle assignment either way.
3. Six FSR pucks (PLA/PETG, 0.2 mm nozzle) — fast, batch these together, good "one more job before
   bed" print.

**The in-person, attended step is electronics assembly (c)** — do this only after both prints
*and* the parts-store items are on hand; there's no point starting wiring with only half the BOM.

---

## (e) Cleaning / post-processing

- **No supports = minimal cleanup.** Light deburr of the drain holes and cutout edges with a
  hobby knife or a fine file — printed round holes through a wall often have a small lip.
- **IPA wipe** the PETG/PLA-CF shell (base + lid) before handling the electronics — clears
  bed-release residue/oils off the surface, standard habit before boards go in.
- **TPU carrier:** no acetone/IPA needed (won't dissolve TPU and doesn't need it). Trim any
  wire-channel stringing with flush cutters.
- **Heat-set inserts (optional, recommended if you'll open the case often):** rather than
  self-tapping an M2.5 screw straight into the post's 2.0 mm pilot hole every time, drill the
  pilot out to ~2.5 mm and press an M2.5 heat-set insert into each standoff post with a soldering
  iron (~200–220 °C for PETG; check your insert's spec if you went PLA-CF). Do this before final
  assembly — much easier with the case empty.
- **Lid fit-check:** press the lid on dry before wiring anything permanently. Too tight → bump
  `tol` up by 0.05–0.1 mm and reprint just the `lid()` half; too loose to click → drop it by the
  same amount. Standard FDM press-fit tuning, same idea as any other snap part in the repo.

---

## (f) Calibration → the existing analysis scripts

Nothing new to build here — this rig reuses the repo's existing pipeline, with one adaptation:

1. **Calibrate** exactly per [`docs/calibration.md`](calibration.md): flash
   [`firmware/fsr_calibrate/`](../firmware/fsr_calibrate/fsr_calibrate.ino) (or your own C6
   equivalent reading `A0`–`A5`), record known weights per sensor, fit with
   [`analysis/calibrate.py`](../analysis/calibrate.py) — same power-law model, same
   `pad_area_mm2` default (122.7 mm² for a 12.5 mm round FSR402 pad), just **6 channels instead
   of 8**.
2. **Zone-count adaptation (the one real code change):** `analyze_pressure.py`, `zone_load.py`,
   `day_summary.py`, and `nerve_fascia.py` all expect 8 FSR columns. Either zero-fill the missing
   `met3`/`toes` columns before feeding a 6-zone log in, or edit each script's `ZONES` list to the
   6-zone set — spelled out with the exact table in
   [`docs/insole_sensor_layout.md`](insole_sensor_layout.md#compatibility-note-for-the-analysis-scripts).
   This mirrors the same kind of small, flagged adaptation `path2_tracking_build.md` already notes
   for its `mode` column — not done yet, just documented so it isn't a surprise.
3. **Run it:**
   ```powershell
   python analysis/analyze_pressure.py "day_*.csv" --calibration calibration.json --out results/
   ```
   Everything downstream (hot-spot detection, the all-day dose, `build_insole.py`'s relief-window
   placement) works unchanged once the 6-zone adaptation above is in — it only reads zone names
   and pressures, not sensor count.

---

**Not a medical device.** FSRs give relative, repeatable pressure — calibrate, read trends,
recalibrate as they drift. Same honest-limits framing as the rest of `docs/`.

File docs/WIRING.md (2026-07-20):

# Wiring — pin-by-pin solder guide for the STEMMA-QT ankle pod

The one thing [`BUILD_PLAN.md`](BUILD_PLAN.md) step (b)/(c) says and doesn't say: it tells you
to wire "the 6 FSR dividers... to a small stub of perfboard" but not which pad gets which lead.
This doc is that missing layer — pin-by-pin, for the **exact hardware in this build**: an
**Adafruit ESP32-C6 Feather** (STEMMA QT), **MPU-6050** + **VCNL4200** STEMMA QT breakouts, **6×
FSR402**, and a flat 1200 mAh LiPo. Read it alongside
[`BUILD_PLAN.md`](BUILD_PLAN.md) §(b)/(c), [`insole_sensor_layout.md`](insole_sensor_layout.md)
(zone numbering), and [`calibration.md`](calibration.md) (the divider math this doc explains the
*build side* of).

Not a medical device — a build reference, same as the rest of `docs/`.

---

## 0. What needs NO soldering — read this first

**The entire I²C sensor chain is plug-in. Zero solder joints.** This is the single biggest labor
saver in the whole build and it's easy to miss because BUILD_PLAN.md's wiring section is titled
the same as the FSR section:

```
ESP32-C6 Feather (STEMMA QT port) ──cable──▶ MPU-6050 (0x68) ──cable──▶ VCNL4200 (0x51)
```

Every connector in that chain is a keyed **JST-SH 4-pin STEMMA QT** plug — SDA/SCL/3V/GND, push
to seat, no tools. **The only soldering in this entire build is the 6 FSR voltage dividers.**
Everything else below in this doc (§1–§8) is exclusively about that FSR wiring.

**Cable inventory gate (you have 1 of 3 needed cables today):** you're holding **one** STEMMA QT
cable, with two more incoming. The chain above needs **two cable hops** — Feather→MPU-6050 and
MPU-6050→VCNL4200 — so with one cable on hand you can seat the Feather→MPU-6050 hop now and bench
test I²C with just the IMU enumerating; hold the VCNL4200 off the chain until cable #2 arrives.
Don't start soldering FSRs waiting on this — the two jobs are independent and the FSR side is the
long pole anyway.

**The BNO085 upgrade path (×3 incoming) — also zero-solder.** When the BNO085 boards arrive, the
MPU-6050→BNO085 swap is a **cable swap, not a rewire**: unplug the STEMMA cable from the MPU-6050,
plug it into the BNO085, done. Two things to check before you do:
- **I²C address.** Adafruit's BNO08x STEMMA QT breakout defaults to `0x4A` (solder-jumper
  selectable to `0x4B`) — **not** `0x68` — so the firmware's I²C address constant needs updating
  when you swap, even though the physical wiring doesn't change.
- **Enclosure fit.** [`ankle_pod_enclosure.scad`](../hardware/ankle_pod_enclosure.scad)'s
  `imu_bay` pocket is sized to the MPU-6050's footprint (`imu_l=18, imu_w=13`). Adafruit's BNO08x
  STEMMA QT board is a noticeably bigger breakout — measure yours against that pocket before you
  assume it drops in; if it doesn't fit, bump `imu_l`/`imu_w` in the `.scad` and reprint just the
  `base()`. Same "measure your actual board" caveat the file already gives for the Feather and
  MPU-6050.

---

## 1. FSR voltage divider — the theory, briefly

An FSR402's resistance **falls** as force on the pad **rises** (roughly 1 MΩ+ unloaded down to a
few hundred ohms at full body weight). Wired into a divider with a **fixed resistor to ground**,
that resistance swing becomes a voltage swing the ADC can read:

```
3V3 ──[ FSR ]── node ──[ R_fixed ]── GND        ADC pin reads "node"
```

```
Vnode = Vcc × R_fixed / (R_fixed + R_fsr)
```

More force → lower `R_fsr` → **higher** `Vnode` (node voltage rises toward 3V3 as the FSR's
resistance shrinks relative to the fixed resistor).

**`R_fixed` sets *where* the divider is most sensitive**, because the curve is steepest (most
`ΔV` per `ΔR_fsr`) right around the force level where `R_fsr ≈ R_fixed`. Pick `R_fixed` too high
and you lose resolution at heavy loads (the curve saturates near 3V3 early); too low and you lose
resolution on light loads (the curve stays pinned near 0V until real force shows up.

**Start at 10 kΩ** — that's the repo-wide default (`calibrate.py --r-fixed` defaults to `10000`,
`vcc` defaults to `3.3`), it's what [`calibration.md`](calibration.md)'s divider model already
assumes, and it centers sensitivity in the light-to-moderate stance-phase range that matters for
this rig. **Tune it after your first calibration pass** ([`calibration.md`](calibration.md) §Do
it once): if `calibrate.py`'s fitted curve for a channel is bunched into the low or high end of
the 0–4095 ADC range instead of spread across it, that channel's `R_fixed` is off — raise it if
the channel never gets far off 0, lower it if it saturates near 4095 well before max stance force.
The ESP32-C6's ADC is 12-bit (0–4095), which is `calibrate.py`'s `--adc-max` default — no flag
needed at the standard 10 kΩ/3.3V setup.

---

## 2. Pin table — FSR zone → divider node → Feather ADC pin

Matches the `fsr0..fsr5` wiring order in [`insole_sensor_layout.md`](insole_sensor_layout.md) and
the CSV column names the firmware logs.

| # | Zone | Divider node | Feather pin | CSV column |
|---|---|---|---|---|
| 0 | `heel_med` | N0 | `A0` | `fsr0` |
| 1 | `heel_lat` | N1 | `A1` | `fsr1` |
| 2 | `midfoot`  | N2 | `A2` | `fsr2` |
| 3 | `met1` | N3 | `A3` | `fsr3` |
| 4 | `met5` | N4 | `A4` | `fsr4` |
| 5 | `hallux` | N5 | `A5` | `fsr5` |

| Rail | Feather pin | Feeds |
|---|---|---|
| 3V3 | `3V` (silkscreened `3V` on the Feather; called `3V3` throughout this repo) | Top leg of all 6 FSRs (shared) |
| GND | `GND` | Bottom leg of all 6 fixed resistors (shared) |

Each zone is **one FSR + one 10 kΩ resistor**, independent of the other five — no mux, no shared
ADC pin, so a solder mistake on one channel can't cross-talk into another.

**Inventory note:** you have 2 of the 12 FSR402 on hand (10 incoming). The divider/solder process
is identical per channel, so there's no reason to wait for all 12 — wire and bench-test whichever
2 zones you have now (e.g. `heel_med`/`heel_lat`, since they share the perfboard's near edge),
confirm the process, then repeat for the rest as they arrive.

---

## 3. Perfboard layout

BUILD_PLAN.md §(b) gives you two options — "a small stub of perfboard, **or** straight to the
Feather's pins." This section specs the perfboard option, since you're holding ELEGOO perfboard;
skip straight to §5 if you're going pin-direct instead (same solder order still applies, just
without the intermediate board).

**Cut a small strip** — roughly 6 columns × a few rows is plenty for 6 resistors and two bus
rails; you don't need a full ELEGOO sheet. It's sized to tuck into `board_clear_h` (the 7 mm of
headroom `ankle_pod_enclosure.scad` reserves above the Feather for "the USB-C plug + STEMMA QT
header + any solder"), sitting along the Feather's **analog-pin edge**. That edge isn't arbitrary
— the enclosure's `sensor_w × sensor_h` (9×4 mm) lead-exit slot is deliberately cut into the −Y
wall "near the Feather's analog-pin edge" (see the `.scad` comment on that cutout) specifically so
the FSR bundle's run from insole → divider → ADC pin is as short as possible.

```
                 3V3 rail ───┬────┬────┬────┬────┬────┬───   (bus wire, one long edge)
                              │    │    │    │    │    │
   from insole,          FSR0  FSR1  FSR2  FSR3  FSR4  FSR5   (FSR leads land here —
   via sensor exit slot        │    │    │    │    │    │      through the −Y wall cutout)
                    node ──────●────●────●────●────●────●──── → jumper up to A0..A5
                              │    │    │    │    │    │      on the Feather header
                             10k  10k  10k  10k  10k  10k     (resistor row)
                              │    │    │    │    │    │
                  GND rail ──┴────┴────┴────┴────┴────┴───   (bus wire, other long edge)
```

- **3V3 and GND rails** run the full length of the strip as two bus wires (or two rows of
  through-holes bridged with solder blobs/bus wire) — one shared 3V3 feed and one shared GND
  return for all 6 dividers, rather than 6 separate rail runs.
- **The 6 signal lines** (the divider nodes) leave the *opposite* long edge from the FSR leads,
  as short jumpers straight down onto the Feather's `A0`–`A5` header pins — this is why the strip
  sits piggybacked directly over that edge rather than off to the side.
- **Strain relief / wire-exit path:** the FSR lead bundle (6 signal + 1 shared 3V3 return, or 6+6
  if you don't bus them at the insole) enters through the `sensor_w × sensor_h` slot on the −Y
  wall, at `main_x0 + main_inner_l*0.68` along the case's length — i.e., already positioned by the
  `.scad` file to land right at this strip. **Anchor the bundle before it reaches the solder
  joints**: a dab of hot glue or a small zip-tie on the bundle just inside the exit slot, so any
  tug on the wire outside the case pulls against the anchor point, not against the joints on the
  perfboard. Leave a short service loop (20–30 mm slack) between the anchor and the perfboard so
  the strip isn't rigidly tethered to the wall.
- **Fit check:** six 22 AWG silicone leads bundled round is roughly a 4–5 mm OD bundle — workable
  through the 9×4 mm slot but not loose. Fan the wires flat (side by side) rather than binding them
  into a round bundle if it's tight; the slot already gets a deburr pass per BUILD_PLAN.md §(e),
  which helps here too.
- If you'd rather skip the perfboard entirely, solder the resistors' leads and the FSR leads
  directly onto/at the Feather's own `A0`–`A5`/`3V3`/`GND` header pins — same electrical result,
  no intermediate board, less to mount but messier to rework.

---

## 4. Solder order — and why it's in this order

1. **Tin all pads and wire ends first** — perfboard pads, resistor leads, wire tips, before you
   join anything. Pre-tinning means each joint only needs a quick reflow, not a full fresh melt —
   less total heat into the board and into the wires per joint.
2. **Resistors first.** They're symmetric, non-polarized, and heat-tolerant, and once they're in
   they physically anchor the strip so it's easier to hold steady for everything that follows.
   Doing them first also means the board isn't yet cluttered with dangling wires while you're
   still getting the resistor row square.
3. **Rails second** (3V3 and GND bus wires connecting all 6 resistor legs). With the resistors
   already anchored, the rail wire has fixed tie-points to solder to instead of floating leads —
   fewer things move while you're working.
4. **Sensor (FSR) leads last.** This is the important ordering choice, not just a convenience:
   FSR tails are the one heat- and time-sensitive joint in this build (§7 below). Doing them last
   means you never have to reheat an FSR joint to attach something else afterward — each FSR tail
   gets touched by the iron exactly once, for the shortest possible dwell time, with a clean tip.
   Doing them first (or interleaved) risks re-melting/re-touching that joint later and cooking the
   tail's conductive ink on the second pass.

**Net effect of this order:** every joint gets touched by the iron the fewest possible times, and
the most heat-fragile joints (FSR tails) get touched last and once — less rework, less risk to the
one component in this build that can't tolerate rework.

---

## 5. Wire gauge, length, and strain relief

- **22 AWG silicone stranded** (what you have) is the right call here — more than enough current
  capacity for these microamp-scale ADC lines, and the reason to use it is mechanical, not
  electrical: silicone jacket stays flexible through repeated ankle flex cycles where PVC-jacketed
  wire stiffens and eventually cracks at the joint. One gauge for both signal and rail wiring also
  keeps the BOM simple.
- **Length:** run each FSR lead from the insole's medial-exit slot (per
  [`insole_fsr_layout.scad`](../hardware/insole_fsr_layout.scad)'s `EXIT_X/EXIT_Y` convergence
  point) up to the ankle pod. As a working estimate for a lower-shin mount, budget **300–400 mm**
  per run plus a **30–50 mm service loop** at *both* ends (insole exit and pod entry) — the ankle
  flexes through its full gait range with this rig on, so a taut, straight-line run stresses the
  solder joints at both ends every step; the loops give the bundle somewhere to take up slack
  instead of pulling on a joint.
- **Heat-shrink every FSR tail joint**, no exceptions — this is the connection that sees the most
  flex-fatigue in the whole build (foot strikes, ankle motion), and a bare joint here is the most
  likely point in the rig to eventually crack from repeated flex. A short piece over the joint,
  shrunk down, turns a point flex stress into a distributed one over the shrink tube's length.
- **Bundle strain relief:** in addition to the anchor point at the enclosure's exit slot (§3),
  anchor the bundle again where it exits the insole carrier, and loosely tape/sleeve the run
  between the two anchors at intervals so it moves as one bundle rather than 6+ independent wires
  snagging separately.

---

## 6. Verify with a multimeter BEFORE powering anything

Do this with the battery **unplugged** and USB **disconnected** — resistance measurements on a
powered board will read garbage (or in the worst case, damage the meter on some ranges).

| Check | How | Expect |
|---|---|---|
| **Continuity, each conductor** | Beep/continuity mode, one probe at the insole-side FSR pad, other at the corresponding perfboard node | Beeps (near-0 Ω) — confirms the wire run itself, end to end |
| **No 3V3↔GND short** | Beep/continuity mode, probe the 3V3 rail vs the GND rail directly on the perfboard | **Should NOT beep.** Even an FSR pressed hard is ~200–400 Ω *in series with* the 10 kΩ resistor (≈10.2–10.4 kΩ total) — far above a continuity tester's ~30–50 Ω beep threshold. If it beeps, you have an actual solder bridge, not a "sensitive" FSR reading |
| **Node → GND (= just `R_fixed`)** | Resistance mode, node pad to GND rail | ~10 kΩ (±resistor tolerance), constant regardless of FSR state — this is really a sanity check that the resistor value/placement is right, not a force reading |
| **Node → 3V3 (= the FSR alone)** | Resistance mode, node pad to 3V3 rail, FSR **unloaded** | **>1 MΩ** — many multimeters will just show `OL` (open). That's correct, not a fault |
| **Node → 3V3, FSR pressed firmly** | Same, press the pad hard by hand | Drops sharply — ballpark **1–3 kΩ** at a firm press, **200–400 Ω** at something close to full body weight on that one pad |

If a channel doesn't show this pattern — no drop under pressure, or already near-zero unloaded —
recheck that channel's joints before it goes anywhere near the case; it's far easier to reflow a
joint on the bench than after the lid's snapped on.

---

## 7. Gotchas

- **Never solder directly to an FSR's exposed tail contacts at high heat.** The tail is a
  conductive-ink-on-flex-film contact, not copper — sustained heat delaminates the ink from the
  substrate and kills that channel permanently, often without any visible sign until it stops
  reading. Some FSR402 variants (including some Adafruit-sourced ones) ship with two pins already
  attached to the tail — if yours do, you don't need to touch the tail at all, just wire onto the
  pins. If yours are bare-tail: use a **low iron temp** (~260–270 °C) with a clean, well-tinned
  tip and get in and out in 2–3 seconds per joint — or skip soldering the tail altogether and use
  a crimp connector / screw terminal / pinch-style header instead. Check which variant you actually
  have before you touch iron to tail.
- **Lead-free solder needs more heat and flows worse than 63/37.** If your solder is RoHS
  lead-free (SAC305 or similar — check what shipped in the iFixit kit), expect to run the iron
  noticeably hotter (~350 °C+) and need more flux for a clean joint than 63/37 leaded solder would
  need — relevant here specifically because the FSR tail joints above want the *opposite*
  (minimum heat, minimum dwell). If you have a choice and local regulations allow it, 63/37 leaded
  solder is the easier, lower-temp, better-flowing choice for those particular joints.
- **IO20 must be driven HIGH for the STEMMA QT connector to power up** — this is a firmware step,
  not a wiring one, but it bites people at the *wiring-verification* stage: if you probe the
  STEMMA QT connector's power pin with a multimeter before flashing firmware, you will correctly
  read **0 V there** even though the board and connector are wired fine — IO20 hasn't been told to
  switch it on yet. Don't chase that as a wiring fault; it resolves the moment firmware runs
  (see [`BUILD_PLAN.md`](BUILD_PLAN.md) §(b) for the full note and source link).

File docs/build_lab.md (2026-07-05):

# Build guide — the two DIY instruments that close the biggest gaps

From [lab_scope.md](lab_scope.md): the insole gives *relative* pressure; these two prints
add the **vertical GRF (× body-weight)** and a **full-foot pressure map** the papers use —
for **~$150** of parts + the H2D. We don't hit lab accuracy; we get the important data at
scale, cheaply, to trend and extrapolate.

## 1 · Force plate — vertical GRF in body-weights
**Unlocks:** the ×BW numbers the insole can't (gymnastics 7–16, jump-landing, running
2.5–3). DIY load-cell rigs reach **ICC > 0.94** vs a lab plate. *(Center-of-pressure too,
if you take the 4-HX711 upgrade — the cheap kit gives total force, which is the key number.)*

**Print** ([`hardware/force_plate.scad`](../hardware/force_plate.scad)): 4× `foot()` +
4× `top_boss()` in PETG (100% infill — they carry load). Top: print `top_plate()` **or**
use a 240 mm plywood/acrylic square (stiffer, faster).

**Buy:** 4× bar load cells (**50 kg** each → 200 kg / ~2000 N capacity) + an **HX711**
amp (a "4× 50 kg load cell + HX711" kit is ~$9), M5 bolts, rubber feet.

**Assemble:** one load cell per corner, **fixed end bolted to a `foot`, free end to the
top** with the air gap so it flexes (don't let it bottom out). Wire the **four cells into
one full bridge** → a single **HX711** → ESP32-S3 (the standard "load-cell combinator"
pattern). *CoP upgrade:* swap in 4 **full-bridge** cells on 4 HX711 for per-corner force.

**Firmware** ([`firmware/force_plate/`](../firmware/force_plate/force_plate.ino)): tares on
boot, streams `t_ms,total_N,total_BW` (flip `COP_MODE` to 1 for the 4-HX711 CoP build).

**Calibrate:** put a known mass on each corner, tune `CAL[i]` until grams read true; set
`BODY_N` to your weight. Then a step/jump onto the plate = a real GRF trace (peak ×BW,
loading rate, CoP) — feed it to the landing/balance analysis by timestamp.

## 2 · Velostat pressure mat — a full-foot pressure map
**Unlocks:** a heel/arch/forefoot **pressure map** (platform-style) to complement the
8-zone insole — great for the standing / seated / bounce work. A maker build resolved
~7,000 cells clearly.

**Print** ([`hardware/pressure_mat.scad`](../hardware/pressure_mat.scad)): the `frame()` —
a rigid border + an **alignment comb** that lays the copper strips straight at `PITCH`
(default 10 mm → ~8×11 = 88 cells for a 110×260 mm mat), plus a cable slot.

**Buy:** a **[Velostat/Linqstat sheet](https://www.adafruit.com/product/1361)** (~$4),
**copper foil tape** (rows + columns), and a **CD74HC4067** mux (you already have a 12-pack)
for the columns.

**Assemble:** lay copper-tape **rows** on the bottom (along the comb), Velostat over them,
copper-tape **columns** on top (crossing). Each overlap = a pressure cell. Rows → ESP32
GPIO; columns → mux → ADC.

**Firmware** ([`firmware/pressure_mat/`](../firmware/pressure_mat/pressure_mat.ino)): drives
one row HIGH at a time, reads every column via the mux, streams a frame per line. Pipe to a
Python heatmap (`matplotlib.imshow` of the row×col array). Caveats in the sketch: **ghosting**
(ground inactive columns or add per-cell diodes) and, for a big matrix, drive rows with a
**74HC595 shift register** instead of one GPIO each.

## 3 · Dial in the accuracy — maker hacks
Cheap sensors drift, ghost, and read blocky — but the maker/research community has field-tested
tricks that recover most of it. The full cited toolbox is [**maker_hacks.md**](maker_hacks.md);
the code-able ones are already baked in:
- **Force plate:** median-then-average filtering + "right SPS for the job" in the firmware.
- **Velostat mat:** an anti-ghosting scan (idle rows sunk LOW + settle-throwaway read) in the
  firmware, and [`analysis/mat_heatmap.py`](../analysis/mat_heatmap.py) to **bicubic-interpolate**
  the coarse grid into a clean pressure map (`--demo` runs with no hardware).
- **FSR insole:** print a [`hardware/fsr_puck.scad`](../hardware/fsr_puck.scad) force-concentrator
  per sensor — the single biggest repeatability win — and calibrate **per sensor**.
- **Everything:** precondition (break it in), ladder-calibrate against known masses, re-tare on drift.

## Honest limits (see [lab_scope.md](lab_scope.md))
Still coarse + resistive (drift → recalibrate); **no shear/6-axis**. But vertical GRF and a
real pressure map, from prints + ~$150, is the data that matters for finding *your* hot
spots and dosing *your* load. r≈0.87, not 1.0 — at scale, that's plenty to extrapolate from.
Not a medical device.

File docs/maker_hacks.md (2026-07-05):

# Maker hacks — squeezing lab-grade data out of $150 of parts

Cheap sensors have **known, documented failure modes**: Velostat and FSRs drift, creep, and
ghost; the HX711 is noisy; a coarse matrix looks blocky. None of that is fatal — the maker /
research community has field-tested tricks that recover most of the accuracy for pennies.
This is that toolbox, each hack tied to the exact problem it fixes and cited to the source.

Ethos (same as [`lab_scope.md`](lab_scope.md)): we're chasing **r≈0.87, not 1.0** — trend-level
truth for *your* foot, cheaply, at scale. The hacks below are what get us from "toy" to "0.87".
The code-able ones are already baked into the firmware + scripts (see the last section).

---

## 0 · Universal (any DIY sensor)

| Problem | Hack | Why / source |
|---|---|---|
| **Break-in drift** — the first minute + first cycles read high/low as the material settles | **Precondition:** cycle the sensor 15–20× to your working load, then discard the first ~60 s of every session before recording | Velostat shows cyclic drift up to **0.00715 V/cycle** and up to a **67% range shift** from cyclic+thermal effects — most of it is early; loading it in first stabilizes the curve ([Velostat in-socket study](https://ieeexplore.ieee.org/document/9024130/)) |
| **Nonlinearity** — raw resistance ≠ force; a single calibration point lies everywhere else | **Ladder-calibrate + per-sensor curve fit:** load a *series* of known masses (1 L water = 1.00 kg; a bathroom scale as ground truth) and fit the power-law `F = a·Gᵇ` **per sensor** | Interlink's own guide: a **per-device parametric curve fit is the most complete calibration**; each FSR varies enough to need its own coefficients ([FSR Integration Guide](https://cdn.sparkfun.com/assets/e/3/b/3/8/force_sensing_resistor_guide.pdf)) |
| **Long-term drift** — the zero and gain wander over days/temperature | **Re-tare on drift, not on a schedule:** watch the empty-baseline; only recalibrate when it exceeds a threshold. Log room temp alongside | Velostat arrays stay usable over **210 days** *if* re-referenced; fixed-schedule recal wastes effort and misses fast drift ([210-day reliability](https://www.researchgate.net/publication/376363749_Investigation_of_the_Long-term_Reliability_of_a_Velostat-Based_Flexible_Pressure_Sensor_Array_for_210_Days)) |
| **Electrical noise** on a 24-bit ADC | **Twist + shorten + shield** every sensor lead; route away from motors / switching supplies / Wi-Fi antenna | Standard HX711 practice — many cheap boards are noisy from long, parallel, unshielded leads ([HX711_ADC notes](https://github.com/olkal/HX711_ADC)) |

---

## 1 · Velostat pressure mat

**The enemy is ghosting (crosstalk).** In a row×column resistive matrix, current sneaks
*backwards* through unpressed cells, so pressing one cell drops the reading of others in its
row and column — and phantom "ghost" cells light up at the crossings.

- **Driven-ground / zero-potential scan (the real fix).** Drive the active row; **hold every
  *other* row AND column at 0 V** so no potential difference exists across the idle cells —
  no sneak current, no ghost. The clean hardware version reads the active column through an
  **op-amp virtual ground** while grounding the rest through analog switches.
  → [Zero-potential method analysis (IET)](https://digital-library.theiet.org/doi/10.1049/iet-smt.2016.0363),
  [Circuit analysis for eliminating crosstalk in pressure mats (Unizar PDF)](https://zaguan.unizar.es/record/133171/files/texto_completo.pdf),
  [Cross-talk compensation in low-cost resistive matrices (TU-Ilmenau)](https://www.tu-ilmenau.de/fileadmin/Bereiche/IA/neurob/Publikationen/conferences_int/2019/Mueller-ICM-2019.pdf).
- **Software-only 80% version** (what's in our firmware): actively drive **all idle rows LOW as
  sinks** (not floating), and after switching the mux, **throw away the first ADC read** so the
  channel settles before you keep a sample. Cheap, no extra parts, kills most of the ghost.
- **Hardware upgrade:** a **Schottky diode in series with each cell** blocks the reverse sneak
  path entirely — the gold standard if you don't want the op-amp. Note the residual limit: even
  the virtual-ground trick leaves *some* crosstalk from the analog-switch on-resistance.
- **Spread the load:** lay a thin firm foam / EVA layer over the matrix so a toe doesn't fall
  *between* electrodes — improves repeatability and stops single-cell spikes.
- **Preload the stack:** a light constant compression (foam + rigid backing) parks Velostat in
  a more linear part of its curve and cuts the creep-to-settle time.

**Resolution hack — interpolate.** An 8×11 mat is blocky, but you don't need more cells to *see*
the hot region: **bicubic-interpolate** the coarse grid up (e.g. → 100×100) for the heatmap.
Bicubic matches linear on error (RMSE ≈ **0.089** vs nearest-neighbor's 0.126) and reads far
cleaner. → [Interpolation techniques for a flexible plantar-pressure mat (IEEE)](https://ieeexplore.ieee.org/document/10101098/),
[FSR plantar pressure + interpolation](https://www.researchgate.net/publication/382404198_Measurement_of_Plantar_Pressures_through_FSR_Sensors_and_Spatial_Resolution_through_Interpolation).
*Done for you:* [`analysis/mat_heatmap.py`](../analysis/mat_heatmap.py) (`--demo`).

---

## 2 · FSR insole (the 8-zone rig)

FSRs are convenient but **hysteretic and drifty** — "drift" here is literally the resistance
changing under a *constant* static load ([Interlink guide](https://cdn.sparkfun.com/assets/e/3/b/3/8/force_sensing_resistor_guide.pdf)).
Tame them:

- **Force concentrator (puck).** Put a small **rigid disc** over the FSR's active area so
  distributed load funnels onto the sensor the *same way every time* — the single biggest
  repeatability win, and it boosts sensitivity. Print [`hardware/fsr_puck.scad`](../hardware/fsr_puck.scad).
- **Firm, flat, smooth backing.** Interlink: mounting an FSR on a **curved** surface pre-loads
  it → lost dynamic range + drift. Keep the sensor sandwiched flat and rigid on the sensing side.
- **Tune the divider resistor R_M to your force band.** In the `Vout = V+ / (1 + R_FSR/R_M)`
  divider, pick R_M so your *actual* forefoot/heel loads land mid-range (not railed high or low).
  For body-weight loads that usually means a **lower** R_M than the datasheet default.
- **Fit each sensor.** Our `calibrate.py` already does the power-law fit — run it **per sensor**,
  not once for the set; FSR-to-FSR spread is large.

---

## 3 · Load-cell force plate

The load cells are the accurate part (**0.1% of capacity** is achievable with a clean mount);
the **HX711 and the mechanics** are where you lose or keep it.

- **Median-*then*-average filter.** A **median** first stage rejects the impulse spikes the
  HX711 throws (10–15× cleaner), *then* a short moving average smooths the rest — averaging alone
  just smears a spike across your readings. → [olkal/HX711_ADC](https://github.com/olkal/HX711_ADC) does
  exactly this (median + moving-average, default 16); [Parallax thread](https://forums.parallax.com/discussion/166836/how-to-filter-noise-on-ad-hx711-load-cell-amp).
  *Baked into* [`force_plate.ino`](../firmware/force_plate/force_plate.ino).
- **Pick the sample rate for the job.** **80 SPS is the *noisiest* rate** — use it *only* for fast
  landing transients where you need the time resolution; for standing, balance, and calibration,
  **10 SPS** is quieter. (Heavy per-sample filtering also caps your effective rate — light filter
  for landings, heavy for quiet stands.)
- **Mechanics decide crosstalk.** Rigid top plate, each load cell's **free end floats in its air
  gap** (don't let it bottom out), fixed end solidly bolted. Off-axis load = false reading.
- **Corner sanity check.** Before trusting the total, press each corner alone and confirm it
  responds — one dead/reversed corner skews the sum (and any CoP).
- **Warm up, then tare.** Let the electronics sit 1–2 min; the HX711 has real thermal drift.
  Tare cold→warm, and re-tare if the empty baseline wanders ([HX711 drift](https://github.com/bogde/HX711/issues/51)).

---

## What's already baked into the repo

| Hack | Where |
|---|---|
| Median-then-average HX711 filter + SPS-for-the-job note | [`firmware/force_plate/force_plate.ino`](../firmware/force_plate/force_plate.ino) |
| Anti-ghost scan (idle rows sunk LOW + settle-throwaway read) + diode/op-amp notes | [`firmware/pressure_mat/pressure_mat.ino`](../firmware/pressure_mat/pressure_mat.ino) |
| Bicubic interpolation of the coarse mat → clean heatmap | [`analysis/mat_heatmap.py`](../analysis/mat_heatmap.py) `--demo` |
| Printable FSR force-concentrator puck | [`hardware/fsr_puck.scad`](../hardware/fsr_puck.scad) |
| Ladder / per-sensor power-law calibration | [`analysis/calibrate.py`](../analysis/calibrate.py) |

**Honest limit (unchanged):** these hacks recover *accuracy and repeatability*, not **shear** or
**6-axis** — that gap stays (see [`lab_scope.md`](lab_scope.md)). And a resistive rig will always
drift more than a capacitive pedar: read **trends**, recalibrate, and don't quote absolutes to a
clinician. Not a medical device.

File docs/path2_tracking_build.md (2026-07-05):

# Path 2 — the all-day pressure-TRACKING build (prep + assembly)

This is the "smart insole" that actually **records** your plantar pressure through the day — **barefoot and in-shoe**, so you can compare the two. It's the optional advanced path (the plain printed insole in Path 1 needs none of this).

## How it physically works
```
  in the shoe / on the foot          at the ankle
  ┌───────────────────────┐          ┌──────────────────┐
  │ sensor carrier (TPU)  │ ribbon   │ ANKLE POD        │
  │  8 FSRs in pockets  ──┼──────────┤ ESP32-S3 + LiPo  │
  │  + IMU-free, flat     │  cable   │ + microSD + IMU  │
  └───────────────────────┘          └──────────────────┘
        wearable / thin                 all the bulk lives here
```
The 3D print does **not** wrap the electronics. Only the thin flat FSRs + wiring go on the foot; the ESP32 + battery + SD live in the **ankle pod** (`hardware/ankle_pod.scad`), joined by a thin ribbon cable.

## Barefoot vs shoe
Two sensor carriers, same pod:
- **Barefoot:** `hardware/barefoot_sole.scad` — a thin soft-TPU footbed strapped to the bare foot.
- **In-shoe:** the same FSR-pocket pattern booleaned into your **scanned insole** (Path 1 model), or the barefoot sole slipped into the shoe.
The firmware tags every row `shoe` or `barefoot` (long-press the button to switch) → the analysis compares how footwear changes your loading + hot spot.

## Battery / how long it lasts
Logging 8 FSRs + IMU to SD at **50 Hz**, the ESP32-S3 draws ~80–120 mA:
| LiPo | Runtime |
|---|---|
| 500 mAh (in your Adafruit cart) | ~4 h (sessions) |
| **1000–1500 mAh** (recommended for all-day) | ~8–14 h |
| 2000 mAh | ~16–20 h |
Not literal 24/7, but a **full waking day** is easy with a 1000–1500 mAh cell. Charge overnight via the pod's USB-C.

## What to add to the parts (beyond the Path 1 printer)
The sensor rig from `parts_list.md` **plus**:
- **Bigger LiPo — 1000–1500 mAh** (JST-PH) for all-day runtime (the 500 mAh is fine for sessions).
- **Thin ribbon / flat cable** (~8–10 conductor) insole → ankle pod.
- Optional: a **2:1 resistor divider** on `PIN_VBAT` (2×100 kΩ) to log battery voltage.

## The three prints
| File | Print in | Notes |
|---|---|---|
| `hardware/ankle_pod.scad` | PLA / PETG | Measure your boards, edit params, F6 → STL |
| `hardware/barefoot_sole.scad` | **soft TPU 85A** | Generic footbed; edit `foot_len`/`foot_w` to you |
| (in-shoe carrier) | soft TPU 85A | Boolean the FSR pockets into your scanned insole for true fit |

## Firmware
Flash **`firmware/all_day_logger/all_day_logger.ino`** (not the session logger):
- Auto-starts, 50 Hz, batched SD writes, BLE off, 80 MHz CPU — tuned for battery.
- Button: **short** = drop an event mark; **long** = toggle shoe ↔ barefoot (starts a new file).
- Files: `day_shoe_00N.csv` / `day_bare_00N.csv`, with a `mode` + `vbat` column.

## Assembly order
1. Print the **ankle pod** + a **barefoot sole**.
2. Seat the 8 FSRs in the sole pockets; route wires down the channels to the ribbon.
3. Wire FSR dividers → mux → ESP32; IMU → I²C; microSD → SPI; LiPo → pod (see main [README](../README.md) Path 2 pin map).
4. Ribbon: sole → pod slot. Close the pod lid. Strap the sole + pod on.
5. Flash the firmware, insert a formatted microSD.

## Daily workflow
1. Charge overnight → strap on in the morning.
2. Wear it; **long-press** to switch shoe/barefoot when you change.
3. End of day: pull the SD card → `python analysis/analyze_pressure.py "day_*.csv" --out results/`.
4. Compare `shoe` vs `barefoot` runs → see how your footwear shifts the hot spot.

> **Analysis note:** the logs carry a `mode` column (shoe/barefoot). `analyze_pressure.py` currently groups by `activity`; point it at `mode` (or rename the column) to split the barefoot-vs-shoe comparison — a small tweak, flagged as TODO.

## Reality check
FSRs give **relative, repeatable** pressure (great for "where + how it shifts"), not lab-grade kPa. All-day comfort depends on good strain relief on the ribbon + a snug (not tight) strap. This is a measurement aid, not a medical device.

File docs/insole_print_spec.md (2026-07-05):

# Insole print spec — variable-density TPU with a targeted relief window

The payoff of the whole lab: a printed insole that is **soft exactly where you hurt, firm where you need support, and hollowed out (offloaded) under the hot spot** the pressure analysis found. Off-the-shelf pads can't do any of that.

Printer: **Bambu H2D** + **TPU High-Flow Kit** (dual nozzle → soft + firm in one print).

## Which 3D-printing process makes a TPU insole?
TPU is a **flexible filament**, so:
- **FDM / FFF (filament)** — melts TPU filament layer by layer. What the **Bambu H2D** does; on the H2D's dual nozzle you get soft cushion + firm shell in one print. **DIY route — this is you.**
- **SLS (powder)** — a laser sinters TPU/nylon *powder*. What **commercial lattice insoles** (HP, Welnove) use — beautiful complex lattices, no supports — but machines run $18k+, so only via a **service bureau**. Great if you outsource and want a premium lattice.
- **Resin (SLA/DLP)** — uses **elastomeric/flexible resins**, *not* true TPU. Fine detail, but soft resins are pricier, messier, and less durable/cushiony for an insole. Skip for this.

**Bottom line:** FDM TPU on the H2D for DIY; SLS via a service only if you want a fancy lattice and don't mind paying per part.

---

## 1. Get the base geometry (scan your orthotic — don't scan a bare foot)
Your existing custom orthotic is a rigid object that already encodes your foot; it scans far better than a soft, moving foot.

1. Matte it (baby powder / matte spray — kill any gloss).
2. Set on newspaper/patterned mat, even light. iPhone: **Scaniverse** or **Polycam** (LiDAR **or** photo). Photo mode = finer detail for a small object.
3. Orbit high + low; flip it, scan the underside too. Include a **ruler/coin** if using pure photogrammetry (for true scale).
4. Export **STL** → clean in Blender/Fusion (remove stray faces, make watertight).

## 2. Zone the insole (from `analysis/results/hotspot.json`)
| Region | Material / nozzle | Lattice | Durometer target |
|---|---|---|---|
| **Heel cushion** (your hot zone) | soft nozzle | gyroid/honeycomb **~12–18%** | soft TPU **~85–90A** or foaming TPU (VarioShore) |
| **Arch / support shell** | firm nozzle | **~35–45%** | **TPU 95A HF** |
| **Forefoot** | soft/medium | ~20–25% | 90–95A |
| **Relief window** (under hot spot) | soft, recessed | see below | — |

## 3. The relief window (the special sauce)
Place it at the **overall_hot_zone** from `hotspot.json` (e.g. `heel_med`):
- A shallow **recess** (1.5–3 mm deep) in the top surface directly under the sore point, **surrounded by a raised "doughnut"** so load transfers to the healthy tissue around it — classic offloading.
- Fill the recess with the **softest lattice** (or leave a thin membrane over a low-density pocket) so it deflects first.
- Keep the window **~15–25 mm** across — big enough to unload the spot, small enough that you don't sink through.

## 4. Design tooling (pick one)
- **Ergono3D** (parametric insole → print-ready STL; add zones) — fastest.
- **Fusion 360 / Blender** — import scan, sculpt top surface, boolean the relief recess, apply variable infill via **modifier meshes** in Bambu Studio (per-zone infill %).
- In **Bambu Studio**: assign the two filaments to the two nozzles; use **modifier volumes** to set infill density per zone and to switch soft↔firm material by region.

## 5. Print settings (starting point, TPU High-Flow hotend)
- Nozzle 235–250 °C, bed 45–55 °C, **0.6 mm hotend** for the cushion (fast, thick, forgiving), 0.4 mm for detail.
- Speed 20–35 mm/s for soft TPU; **infill = honeycomb** (best energy absorption) in cushion zones.
- Feed soft/foaming TPU from an **external spool** (not AMS). VarioShore: print ~10–20 °C hotter to trigger foaming, slower flow → softer.
- Walls 2–3, top/bottom 3–4 so the lattice doesn't telegraph through.

## 6. Sensor-carrier version (for measuring, before/after)
Print a **second, thin (2–3 mm) flat TPU insole** with **8 shallow pockets** at the `SENSOR_XY` positions to seat the FSR402 pads, plus a routed channel to the instep for the wiring bundle. Slide it under your normal insole to record → this is what generates the logs `analyze_pressure.py` reads.

## 7. ESP32 enclosure
Small printed clip-on box (PLA/PETG fine here — no flex needed) for the ESP32-S3 + LiPo + SD, worn at the ankle/laces. Include: USB-C cutout, a hole for the button (GPIO14), a light pipe for the LED (GPIO15), and a slot for the sensor ribbon.

---

## The loop
1. Print **sensor-carrier** → record `stand/walk/stairs/pivot` → `analyze_pressure.py` → get **hot zone**.
2. Print **insole v1** with the relief window at that zone.
3. Re-record **with v1 installed** → confirm peak + impulse at the hot zone **dropped**.
4. Not enough? Enlarge/soften the window, drop cushion infill 3–5%, reprint. Repeat until the hot-zone impulse flattens out.

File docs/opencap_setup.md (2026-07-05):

# OpenCap setup — markerless gait across movements (iPhone)

[OpenCap](https://www.opencap.ai/) (Stanford) turns **2 iPhones/iPads** into a 3D markerless motion-capture lab: joint angles, gait speed, stride length, cadence — even estimated joint moments via an OpenSim backend. Free, cloud-processed. 2026 studies report **good-to-excellent within-device reliability** for gait metrics (best when averaging 3 trials).

## You need
- **2 iOS devices** (iPhone/iPad). Any modern iPhone works — LiDAR not required (OpenCap uses the RGB cameras + pose estimation). If you only have one, use **Kinovea** (free desktop 2D) until you borrow a second.
- **2 tripods** (or lean/mount at ~waist height, ~1.5–2 m apart, both aimed at the capture zone).
- The **OpenCap iOS app** (App Store) + a free account at app.opencap.ai.
- A printed **checkerboard** (the app links the PDF) for calibration — tape it to stiff card.

## Capture workflow
1. **Create a session** at app.opencap.ai → it shows a QR/session code.
2. **Connect both iPhones** by scanning the session in the OpenCap app. Mount them ~60–90° apart covering the walkway.
3. **Calibrate**: place the checkerboard in view of both cameras; capture the calibration frame.
4. **Neutral pose**: one static A-pose/T-pose trial (defines your body model + scaling).
5. **Record movements** — one trial each, 3 reps is ideal for reliability:
   - level walk (slow + self-selected + fast)
   - stairs up / down
   - pivot / cut
   - single-leg stance / mini-squat
6. Trials auto-upload → OpenSim processing → download **joint kinematics** (and kinetics) as CSV/`.mot`.

## What to pull out (feeds the insole)
- **Ankle/subtalar angle** through stance → pronation/supination tendency (informs any medial/lateral **posting**).
- **Foot progression + strike pattern** (heel vs mid/forefoot) → where along the foot load lands.
- **Stance-time & loading asymmetry** L vs R → whether one side needs more cushioning.
- **How all of the above change by activity** → so the insole is tuned for your real movements, not just standing.

## Syncing with the smart insole
Start an insole recording (`smart_insole.ino`, short button press) and clap/stomp once at the start of each OpenCap trial — the stomp is a spike in both the insole accel (`ax/ay/az`) and the OpenCap kinematics, so you can time-align the two streams in `analyze_pressure.py` later.

## Fallbacks / alternatives
- **Kinovea** (free, Windows) — 2D sagittal video: quick heel-strike/toe-off, joint angle overlays, one camera.
- **OnForm / Plask** — phone 2D quick looks.
- OpenCap remains the only free route to **3D joint-level** data across movements.

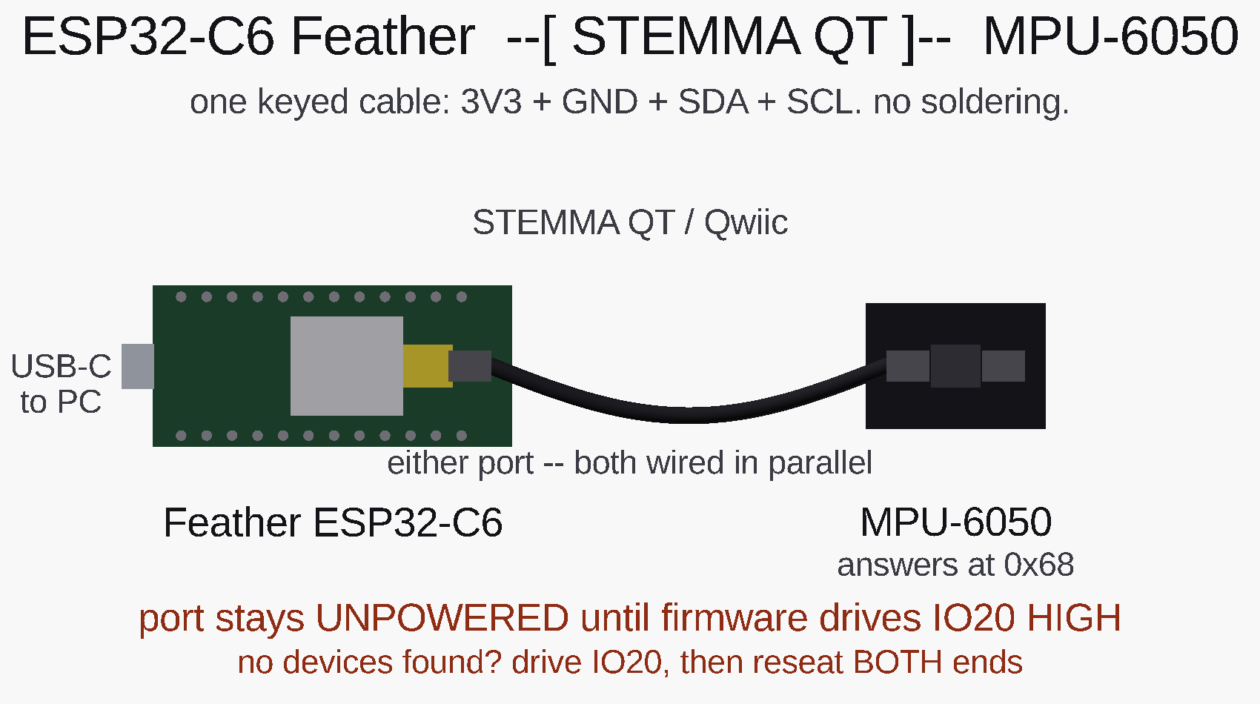
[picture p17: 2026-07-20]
docs/wiring_top.png

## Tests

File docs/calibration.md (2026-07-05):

# Calibration — turn the FSRs into real pressure (kPa)

FSRs are **nonlinear**, so raw ADC ≠ force. This one-time step fits each sensor's
curve from known weights, so the analysis reports **real kPa** instead of relative units.

## The model (what's happening)
1. **ADC → resistance.** From the voltage divider (`3V3 — FSR — node — 10 kΩ — GND`, ADC reads the node): `R_fsr = R_fixed · (Vcc − Vout) / Vout`.
2. **Resistance → conductance** `G = 1/R` (roughly proportional to force).
3. **Conductance → force**, per sensor, via a fitted power law **`F = a · G^b`** (`calibrate.py` finds `a, b`).
4. **Force → pressure** `P(kPa) = F(N) / pad_area(m²) / 1000`. Default pad area = **122.7 mm²** (a 12.5 mm round FSR) — set `--pad-area-mm2` to yours.

## Do it once (~20 min)
1. **Flash** [`firmware/fsr_calibrate/`](../firmware/fsr_calibrate/fsr_calibrate.ino), open Serial Monitor @115200 — it streams `fsr0..fsr7`.
2. For **each sensor**, rest a **known weight** squarely on the pad and note that column's ADC. Use ~4–6 weights across the range (e.g., 0.5, 1, 2, 5, 10 kg). `force_N = mass_kg × 9.81`.
   - A small flat cap over the pad spreads the load; keep it centered.
3. Record rows in a CSV (see [`analysis/cal_points_template.csv`](../analysis/cal_points_template.csv)):
   ```
   sensor,force_N,adc
   0,9.81,1500
   0,49.0,3350
   ...
   ```
4. **Fit:**
   ```powershell
   python analysis/calibrate.py cal_points.csv --out calibration.json
   ```
   It prints `a b R2 n` per channel — **aim for R² > 0.95**. Add more weight points to any low-R² channel.
5. **Use it** — the analysis now reports kPa:
   ```powershell
   python analysis/interpret.py       "day_*.csv" --calibration calibration.json --out results/
   python analysis/analyze_pressure.py "day_*.csv" --calibration calibration.json --out results/
   ```

## Accuracy notes (honest)
- Even calibrated, FSRs are **±10–20%** absolute — great for *trends, hot spots, before/after*, not lab-grade metrology.
- Calibrate **in situ** if you can (sensor mounted in the sole), since the mounting surface affects response.
- Re-check occasionally; FSRs drift with heavy use.
- No calibration? The analysis still works in **relative units** — you just lose the kPa axis.

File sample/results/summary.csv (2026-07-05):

activity | samples | hot_zone | hot_peak | hot_impulse | peak_heel_med | peak_heel_lat | peak_midfoot | peak_met1 | peak_met3 | peak_met5 | peak_hallux | peak_toes | impulse_heel_med | impulse_heel_lat | impulse_midfoot | impulse_met1 | impulse_met3 | impulse_met5 | impulse_hallux | impulse_toes | n_steps | cadence_spm | stride_s
barefoot | 1500 | heel_med | 401.2 | 1534.7 | 401.2 | 250.4 | 89.4 | 137.6 | 122.2 | 85.7 | 116.5 | 72.8 | 1534.7 | 1110.9 | 519.5 | 673.2 | 589.6 | 440.7 | 496.7 | 308.3 | 27 | 54.5 | 1.101
shoe | 1500 | heel_med | 645.4 | 2454.8 | 645.4 | 265.0 | 69.4 | 120.3 | 101.7 | 68.3 | 94.3 | 50.4 | 2454.8 | 1184.3 | 420.0 | 593.9 | 507.4 | 356.7 | 423.4 | 236.7 | 27 | 54.5 | 1.101

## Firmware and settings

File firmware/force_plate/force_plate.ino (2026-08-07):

/*
 * force_plate.ino — pressure/force acquisition for biomech-pressure-lab.
 * ============================================================================
 * Load cells (HX711) + FSR pucks -> calibrated newtons -> condition-tagged CSV
 * on Serial and (when a card reader exists) on microSD.
 *
 * Board:  ESP32-WROOM-32 DevKitC  (Elegoo ESP-32 3-pack)   esp32:esp32:esp32
 *         The ESP32-C6 Feather is NOT used here — SENSING_DEVICES_PLAN.md:587
 *         assigns the Feather to the worn insole+ankle pod (N1). The force
 *         plate gets a plain devkit, per FIRMWARE_SCOPE.md's board assignment.
 *
 * ----------------------------------------------------------------------------
 * WHAT THIS IS NOT, AND WHY THAT IS IN THE FIRMWARE AND NOT JUST THE DOCS
 * ----------------------------------------------------------------------------
 * hardware/BENCH_NEXT_STEPS.md §0 established two things about the parts that
 * are physically on the desk today:
 *
 *   - `force_plate.stl` is ONE `foot()` bracket (19.0 x 26.0 x 21.0 mm), not a
 *     plate. The rig needs 4 feet + 4 top_bosses + a top. You have 1 / 0 / 0.
 *   - That foot printed in plain PETG at <=52 % effective density, against a
 *     PRINT_CARD spec of PA-CF/PETG-CF at 100 % infill. It is a dimensional
 *     fit-check coupon.
 *
 * So NOBODY STANDS ON THIS. That is not a disclaimer, it is enforced below by
 * MAX_BENCH_N: any total above 250 N latches an overload fault, stops logging,
 * and requires an explicit CLEAR. 250 N is ~25 kg — comfortably above any
 * hand-press or bench mass you would legitimately use, and far below the ~779 N
 * a single sole sees. Reduced protective sensation (T1DM) means the operator
 * may not feel a corner bracket digging in or a rig starting to fail, so the
 * ceiling lives in code where it does not depend on being felt.
 *
 * ----------------------------------------------------------------------------
 * SAFETY POSTURE — hEDS + T1DM as firmware constraints
 * ----------------------------------------------------------------------------
 *  * NOTHING HERE HEATS, VIBRATES OR MOVES. This subsystem drives no motor, no
 *    heater, no servo, no haptic. The only output pin is the 3 mA status LED.
 *    There is therefore no duty-cycle bound to state, because there is no duty
 *    to bound — that is the honest answer, not an omission.
 *  * HARD INPUT LIMIT: MAX_BENCH_N (250 N), latching. See above.
 *  * SESSION CAP: MAX_SESSION_MS (20 min), auto-stop. An unattended rig pressing
 *    on an insensate foot is the failure this bounds.
 *  * TASK WATCHDOG: 8 s, panic-on-timeout, fed once per loop. Every HX711 read
 *    is timeout-guarded (hx711_lite.h), so an absent or miswired amp reports
 *    #FAULT hx711_timeout instead of hanging in a way that looks like "no load".
 *  * The HX711 excites the bridge at ~4.3 V through ~1 k, i.e. ~4 mA. No thermal
 *    path to skin exists in this circuit at all.
 *
 * ----------------------------------------------------------------------------
 * CONDITIONS ARE COORDINATES — enforced, not requested
 * ----------------------------------------------------------------------------
 * A force trace with no posture / load / footwear attached is not data, it is a
 * number. START is REFUSED until all five condition fields are set, every row
 * carries a cond_id, and changing any field mid-session increments cond_id and
 * rolls to a new SD file. Bring-up without a condition is still possible via
 * RAW, which is prefixed #RAW, is never written to SD, and is not CSV.
 *
 * ----------------------------------------------------------------------------
 * BUGS FIXED FROM THE PREVIOUS REVISION OF THIS FILE (all real, all silent)
 * ----------------------------------------------------------------------------
 *  B1. `#include "HX711.h"` — library not installed on this machine, so this
 *      sketch did not compile at all. Replaced by hx711_lite.h (no dependency).
 *  B2. DOUT_PIN was GPIO5 — an ESP32 STRAPPING pin. HX711 DOUT is pulled LOW
 *      whenever a conversion is ready, so a powered amp can hold GPIO5 low
 *      across reset and change the boot mode.
 *  B3. The COP_MODE pin map was DOUT[4] = {5, 6, 7, 15}. GPIO6 and GPIO7 are
 *      bonded to the WROOM-32's internal SPI FLASH — driving them crashes the
 *      chip. GPIO15 is a second strapping pin. Three of those four pins were
 *      unusable, which is what happens to a code path nobody could build.
 *  B4. `const float BODY_N = 700.0` hard-coded a body weight and divided every
 *      reported value by it. analysis/balance.py already refuses to scale by an
 *      unsourced body constant (see its FOOT_L_MM enforcement note). Body mass
 *      is now UNSET by default; bw_ratio is emitted empty until BW <kg> is given
 *      and the value is recorded in the file header.
 *  B5. No read timeout anywhere -> indefinite hang on a missing amp.
 *  B6. Calibration lived in a source constant, so it was lost on every reflash.
 *      Offsets and scale factors now persist in NVS.
 *
 * ----------------------------------------------------------------------------
 * UNTESTED ON HARDWARE. Compiles clean (see README §7 for the exact command and
 * byte count). It has never been flashed, no serial port has been opened, and
 * no HX711, load cell or FSR has been connected. Treat every number it prints
 * as unverified until the bench procedure in README §6 has been run.
 * ============================================================================
 */

#include <Arduino.h>
#include <Preferences.h>
#include <SPI.h>
#include <SD.h>
#include <time.h>
#include <sys/time.h>
#include "esp_task_wdt.h"
#include "hx711_lite.h"

// ===========================================================================
// 1. BUILD CONFIGURATION
// ===========================================================================

#define FW_NAME     "force_plate"
#define FW_VERSION  "2.0.0"
#define FW_DATE     "2026-08-07"

// --- Acquisition mode ------------------------------------------------------
// MODE_TOTAL  1x HX711, channel A. Four 50 kg HALF-bridge cells combined into
//             ONE full Wheatstone bridge (the bathroom-scale topology that the
//             owned ~$8.49 kit actually is). Gives TOTAL vertical force only.
//             *** THIS IS THE ONLY MODE THE OWNED HARDWARE SUPPORTS. ***
//             ergonomics/carts/INVENTORY.md:259 and FIRMWARE_SCOPE.md's parts
//             ledger both record "4x 50 kg load cell + HX711 | 1 set" — ONE
//             amplifier. Not four. That count is what decides total-force vs
//             centre-of-pressure, and it decides total-force.
//
// MODE_AP     1x HX711, channels A AND B. The four half-bridge cells are split
//             into TWO full bridges (front pair, rear pair) instead of one.
//             Yields total force PLUS a 1-D anterior/posterior CoP with zero
//             purchase. Channel B's gain is FIXED at 32 vs A's 128, so the rear
//             line is ~4x coarser — real, but not equivalent to a 4-cell rig.
//             UNTESTED, and it requires rewiring the cell harness.
//
// MODE_COP4   4x HX711 sharing a clock. Full 2-D centre of pressure. Needs
//             3 MORE HX711 amplifiers (~$9 total) -> see README §8 CART. The
//             code is here and compiles; the parts are not on the shelf.
#define MODE_TOTAL 0
#define MODE_AP    1
#define MODE_COP4  2

#ifndef ACQ_MODE
#define ACQ_MODE MODE_TOTAL
#endif

// --- Safety ceilings. These are the hard limits; do not raise them casually. -
static const float    MAX_BENCH_N     = 250.0f;      // latching overload trip
static const uint32_t MAX_SESSION_MS  = 20UL * 60UL * 1000UL;   // 20 min cap
static const uint32_t WDT_TIMEOUT_MS  = 8000;
// Set to 1 ONLY after the rig has been proof-loaded and reprinted to the
// PRINT_CARD structural spec. It gates nothing electrical; it gates the banner
// and the overload ceiling, and it is deliberately awkward to flip.
#define ALLOW_BODY_LOAD 0

// ===========================================================================
// 2. PIN MAP — ESP32-WROOM-32 DevKitC
// ===========================================================================
// Chosen against the WROOM-32 constraints, not by convenience:
//   - GPIO6..11  : bonded to internal SPI flash. NEVER USE. (killed the old B3)
//   - GPIO0,2,12,15 : strapping pins. Avoided for anything an external part drives.
//   - GPIO34..39 : INPUT-ONLY, no pull-ups. Perfect for HX711 DOUT, which is a
//                  push-pull output from the amp and needs no pull-up.
//   - GPIO32..39 : ADC1. Usable with WiFi on; ADC2 is not. FSRs go here.
//   - GPIO5      : VSPI default CS. It IS a strapping pin, but CS idles HIGH,
//                  which is the level the strap wants, so it is safe as CS.

static const int PIN_HX_SCK   = 27;   // shared PD_SCK for every HX711
static const int PIN_HX_DOUT0 = 34;   // amp 0 — the only one the kit provides
static const int PIN_HX_DOUT1 = 35;   // amps 1..3 are MODE_COP4 only (not owned)
static const int PIN_HX_DOUT2 = 36;
static const int PIN_HX_DOUT3 = 39;

static const int PIN_FSR_A    = 32;   // ADC1_CH4 — fsr_puck / FSR402 #1
static const int PIN_FSR_B    = 33;   // ADC1_CH5 — FSR402 #2

static const int PIN_SD_CS    = 5;    // VSPI
static const int PIN_SD_SCK   = 18;
static const int PIN_SD_MOSI  = 23;
static const int PIN_SD_MISO  = 19;

static const int PIN_LED      = 2;    // onboard blue LED, ~3 mA. Only output pin.

#if ACQ_MODE == MODE_COP4
static const int N_CELLS = 4;
#elif ACQ_MODE == MODE_AP
static const int N_CELLS = 2;         // two logical channels on one amp
#else
static const int N_CELLS = 1;
#endif

// ===========================================================================
// 3. STATE
// ===========================================================================

HX711Lite  hx[4];
Preferences prefs;

// --- Calibration, persisted in NVS -----------------------------------------
struct CellCal {
  int32_t offset;      // raw counts at zero load (tare)
  float   scale_cpn;   // counts per NEWTON. 0 => uncalibrated.
};
CellCal cal[4] = {{0, 0.0f}, {0, 0.0f}, {0, 0.0f}, {0, 0.0f}};

float plate_ap_mm = 240.0f;   // front-line to rear-line spacing (force_plate.scad PLATE)
float plate_ml_mm = 240.0f;
float body_kg     = 0.0f;     // 0 => UNSET. bw_ratio stays blank. See B4.

// --- Condition. Conditions are coordinates: none of these may be empty. -----
struct Condition {
  char posture[24];   // stand_2ft | stand_1ft_L | stand_1ft_R | seated | press_hand
  char load[24];      // bw_full | bw_partial | mass_only | hand
  char footwear[24];  // barefoot | sock | shoe_<name> | orthotic_<name>
  char side[8];       // L | R | both | na
  char surface[24];   // hard | foam | carpet | plate_bare
  char note[48];
};
Condition cond = {"", "", "", "", "", ""};
uint16_t cond_id = 0;

// --- Session ---------------------------------------------------------------
uint32_t session_no   = 0;
bool     streaming    = false;
bool     raw_mode     = false;
uint32_t session_t0   = 0;
uint16_t sample_win   = 5;      // median-trim window, 1..15
uint32_t row_count    = 0;

bool  sd_present      = false;
File  logfile;
char  logpath[40]     = "";

// --- Fault flags emitted on every row --------------------------------------
static const uint16_t F_HX_TIMEOUT   = 0x0001;
static const uint16_t F_HX_SAT       = 0x0002;
static const uint16_t F_OVERLOAD     = 0x0004;
static const uint16_t F_NOT_TARED    = 0x0008;
static const uint16_t F_NOT_CAL      = 0x0010;
static const uint16_t F_COND_UNSET   = 0x0020;
static const uint16_t F_SD_FAIL      = 0x0040;
static const uint16_t F_EPOCH_UNSET  = 0x0080;
static const uint16_t F_SESSION_CAP  = 0x0100;

uint16_t sticky_flags = 0;
bool     overload_latched = false;
bool     epoch_set = false;

// ===========================================================================
// 4. HELPERS
// ===========================================================================

static float trimmedMean(float *b, int n) {
  // maker hack, docs/maker_hacks.md: median-then-trimmed-mean. A plain average
  // SMEARS the HX711's impulse spikes across the window; sorting and dropping
  // the outer quartiles rejects them first. Kept from the previous revision
  // because it is the right filter — only the plumbing around it changed.
  for (int i = 1; i < n; i++) {
    float k = b[i]; int j = i - 1;
    while (j >= 0 && b[j] > k) { b[j + 1] = b[j]; j--; }
    b[j + 1] = k;
  }
  int lo = n / 4, hi = n - n / 4;
  if (hi <= lo) { lo = 0; hi = n; }
  float s = 0;
  for (int i = lo; i < hi; i++) s += b[i];
  return s / (float)(hi - lo);
}

// Read one logical channel as RAW counts, averaged over `n` conversions.
// Returns false and sets flags if the amp does not answer.
static bool readCellRaw(int ch, int n, float &outRaw, uint16_t &flags) {
  if (n < 1) n = 1;
  if (n > 15) n = 15;
  float buf[15];
  int got = 0;

  for (int i = 0; i < n; i++) {
#if ACQ_MODE == MODE_AP
    // One amp, two channels: A = front pair, B = rear pair. switchGain() burns
    // one conversion because the HX711 applies gain to the NEXT sample.
    HX711Lite::Gain want = (ch == 0) ? HX711Lite::GAIN_A_128 : HX711Lite::GAIN_B_32;
    if (hx[0].gain() != want) {
      if (!hx[0].switchGain(want)) { flags |= F_HX_TIMEOUT; break; }
    }
    int amp = 0;
#else
    int amp = ch;
#endif
    int32_t r;
    if (!hx[amp].readRaw(r)) { flags |= F_HX_TIMEOUT; break; }
    if (HX711Lite::saturated(r)) flags |= F_HX_SAT;
    buf[got++] = (float)r;
  }

  if (got == 0) return false;
  outRaw = trimmedMean(buf, got);
  return true;
}

static bool conditionComplete() {
  return cond.posture[0] && cond.load[0] && cond.footwear[0]
      && cond.side[0] && cond.surface[0];
}

static void isoUtc(char *buf, size_t n) {
  if (!epoch_set) { snprintf(buf, n, ""); return; }
  time_t now = time(nullptr);
  struct tm tmv;
  gmtime_r(&now, &tmv);
  strftime(buf, n, "%Y-%m-%dT%H:%M:%SZ", &tmv);
}

static void saveCal() {
  prefs.begin("fplate", false);
  for (int i = 0; i < 4; i++) {
    char k[12];
    snprintf(k, sizeof(k), "off%d", i); prefs.putInt(k, cal[i].offset);
    snprintf(k, sizeof(k), "scl%d", i); prefs.putFloat(k, cal[i].scale_cpn);
  }
  prefs.putFloat("ap_mm", plate_ap_mm);
  prefs.putFloat("ml_mm", plate_ml_mm);
  prefs.putFloat("bodykg", body_kg);
  prefs.end();
  Serial.println("#OK cal saved to NVS");
}

static void loadCal() {
  prefs.begin("fplate", true);
  for (int i = 0; i < 4; i++) {
    char k[12];
    snprintf(k, sizeof(k), "off%d", i); cal[i].offset    = prefs.getInt(k, 0);
    snprintf(k, sizeof(k), "scl%d", i); cal[i].scale_cpn = prefs.getFloat(k, 0.0f);
  }
  plate_ap_mm = prefs.getFloat("ap_mm", 240.0f);
  plate_ml_mm = prefs.getFloat("ml_mm", 240.0f);
  body_kg     = prefs.getFloat("bodykg", 0.0f);
  prefs.end();
}

static uint32_t nextSession() {
  prefs.begin("fplate", false);
  uint32_t s = prefs.getUInt("sess", 0) + 1;
  prefs.putUInt("sess", s);
  prefs.end();
  return s;
}

static const char *modeName() {
#if ACQ_MODE == MODE_COP4
  return "COP4";
#elif ACQ_MODE == MODE_AP
  return "AP";
#else
  return "TOTAL";
#endif
}

// ===========================================================================
// 5. CSV / LOG FORMAT
// ===========================================================================
// One header block of '#' comment lines, then one #COLS line, then plain CSV.
// Every consumer in analysis/ already skips '#'. The `activity` column is the
// posture verbatim, which is what analysis/balance.py's group_col() looks for.
//
//   t_ms       ms since boot, monotonic. ALWAYS present, never wrong.
//   iso_utc    wall clock, empty unless TIME <epoch> was sent. There is NO RTC
//              on this machine (ergonomics/carts/INVENTORY.md has no RTC row),
//              so wall time can only come from the host. An empty column is the
//              truthful answer, not a fabricated one.
//   sess       NVS session counter, survives reflash
//   cond_id    increments on ANY condition change; joins a row to its coordinates
//   activity   = cond.posture
//   total_n    calibrated total vertical force, newtons
//   ch0_n..    per-channel force, newtons (MODE_AP: front/rear; COP4: 4 corners)
//   cop_ap_mm  anterior/posterior CoP, blank in MODE_TOTAL (1 channel = no CoP)
//   cop_ml_mm  medial/lateral CoP, MODE_COP4 only
//   bw_ratio   total_n / (body_kg*9.80665); BLANK while body_kg is unset (B4)
//   fsr0_adc   raw 12-bit ADC — the column analysis/calibrate.py expects
//   fsr0_mv    calibrated millivolts from analogReadMilliVolts(); better data,
//              added alongside rather than replacing, so the existing fit still runs
//   flags      hex bitmask, see section 3

static void writeHeader(Print &p) {
  char iso[28]; isoUtc(iso, sizeof(iso));
  p.printf("# %s v%s (%s)  mode=%s  cells=%d\n", FW_NAME, FW_VERSION, FW_DATE, modeName(), N_CELLS);
  p.printf("# session=%lu  boot_ms=%lu  iso_utc=%s\n", (unsigned long)session_no, (unsigned long)millis(), iso);
  p.printf("# cond_id=%u posture=%s load=%s footwear=%s side=%s surface=%s note=%s\n",
           cond_id, cond.posture, cond.load, cond.footwear, cond.side, cond.surface, cond.note);
  p.printf("# body_kg=%s\n", body_kg > 0 ? String(body_kg, 2).c_str() : "UNSET");
  p.printf("# geom_ap_mm=%.1f geom_ml_mm=%.1f win=%u\n", plate_ap_mm, plate_ml_mm, sample_win);
  for (int i = 0; i < N_CELLS; i++)
    p.printf("# cal%d offset=%ld scale_counts_per_N=%.4f\n", i, (long)cal[i].offset, cal[i].scale_cpn);
  p.printf("# max_bench_n=%.1f session_cap_ms=%lu allow_body_load=%d\n",
           MAX_BENCH_N, (unsigned long)MAX_SESSION_MS, ALLOW_BODY_LOAD);
  p.println("# UNVERIFIED: this firmware has never been run against a physical HX711.");
  p.println("#COLS t_ms,iso_utc,sess,cond_id,activity,total_n,ch0_n,ch1_n,ch2_n,ch3_n,"
            "cop_ap_mm,cop_ml_mm,bw_ratio,fsr0_adc,fsr0_mv,fsr1_adc,fsr1_mv,flags");
}
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
void loop() {
  esp_task_wdt_reset();
  pollSerial();

  if (raw_mode) {
    static uint32_t tr = 0;
    if (millis() - tr >= 200) {
      tr = millis();
      for (int c = 0; c < N_CELLS; c++) {
        float raw; uint16_t f = 0;
        if (readCellRaw(c, 1, raw, f)) Serial.printf("#RAW ch%d=%.0f ", c, raw);
        else                           Serial.printf("#RAW ch%d=TIMEOUT ", c);
      }
      Serial.printf("fsrA=%d fsrB=%d\n", analogRead(PIN_FSR_A), analogRead(PIN_FSR_B));
    }
    return;
  }

  if (!streaming) { digitalWrite(PIN_LED, (millis() / 1000) % 2); return; }

  // --- session cap: an unattended rig on an insensate foot is what this bounds
  if (millis() - session_t0 > MAX_SESSION_MS) {
    sticky_flags |= F_SESSION_CAP;
    Serial.printf("#LIMIT session cap %lu ms reached - auto-stop\n", (unsigned long)MAX_SESSION_MS);
    cmdStop();
    return;
  }

  uint16_t flags = sticky_flags;
  if (!conditionComplete()) flags |= F_COND_UNSET; else flags &= ~F_COND_UNSET;

  float n_ch[4] = {0, 0, 0, 0};
  float total_n = 0;
  bool  any = false;

  for (int c = 0; c < N_CELLS; c++) {
    float raw;
    if (!readCellRaw(c, sample_win, raw, flags)) { n_ch[c] = NAN; continue; }
    any = true;
    n_ch[c] = (cal[c].scale_cpn != 0.0f) ? (raw - (float)cal[c].offset) / cal[c].scale_cpn : NAN;
    if (!isnan(n_ch[c])) total_n += n_ch[c];
  }

  if (!any) {
    Serial.println("#FAULT every HX711 timed out - stopping. Check VCC, E+/E-, DOUT, CLK.");
    cmdStop();
    return;
  }

  // --- HARD LIMIT. Latching, and it stops the session. ----------------------
  if (total_n > MAX_BENCH_N && !overload_latched) {
    overload_latched = true;
    sticky_flags |= F_OVERLOAD;
    flags |= F_OVERLOAD;
    Serial.printf("#ALERT OVERLOAD %.1f N > %.1f N ceiling. LOGGING STOPPED.\n", total_n, MAX_BENCH_N);
    Serial.println("#ALERT This rig is a fit coupon, not a force plate. Take the load off.");
    Serial.println("#ALERT Send CLEAR to reset once the load is removed.");
    digitalWrite(PIN_LED, HIGH);
    cmdStop();
    return;
  }

  // --- CoP -----------------------------------------------------------------
  float cop_ap = NAN, cop_ml = NAN;
#if ACQ_MODE == MODE_AP
  // Two measurement lines: front pair at y=0, rear pair at y=plate_ap_mm.
  if (total_n > 1.0f && !isnan(n_ch[0]) && !isnan(n_ch[1]))
    cop_ap = (n_ch[1] * plate_ap_mm) / total_n;
#elif ACQ_MODE == MODE_COP4
  // Corner order: 0 = front-left, 1 = front-right, 2 = rear-left, 3 = rear-right.
  if (total_n > 1.0f) {
    float fl = n_ch[0], fr = n_ch[1], rl = n_ch[2], rr = n_ch[3];
    if (!isnan(fl) && !isnan(fr) && !isnan(rl) && !isnan(rr)) {
      cop_ap = ((rl + rr) * plate_ap_mm) / total_n;
      cop_ml = ((fr + rr) * plate_ml_mm) / total_n;
    }
  }
#endif

  int   fsr0 = analogRead(PIN_FSR_A);
  int   fsr1 = analogRead(PIN_FSR_B);
  int   mv0  = analogReadMilliVolts(PIN_FSR_A);
  int   mv1  = analogReadMilliVolts(PIN_FSR_B);

  char iso[28]; isoUtc(iso, sizeof(iso));
  char bw[16] = "";
  if (body_kg > 0) snprintf(bw, sizeof(bw), "%.3f", total_n / (body_kg * 9.80665f));

  char row[256];
  int len = snprintf(row, sizeof(row),
    "%lu,%s,%lu,%u,%s,%.2f,%.2f,%.2f,%.2f,%.2f,%s,%s,%s,%d,%d,%d,%d,0x%04X",
    (unsigned long)millis(), iso, (unsigned long)session_no, cond_id, cond.posture,
    total_n, n_ch[0], n_ch[1], n_ch[2], n_ch[3],
    isnan(cop_ap) ? "" : String(cop_ap, 1).c_str(),
    isnan(cop_ml) ? "" : String(cop_ml, 1).c_str(),
    bw, fsr0, mv0, fsr1, mv1, flags);

  Serial.println(row);
  if (logfile) {
    logfile.println(row);
    if ((++row_count % 20) == 0) logfile.flush();   // bounded data loss on a yank
  } else {
    row_count++;
  }

  digitalWrite(PIN_LED, (row_count & 1));
}

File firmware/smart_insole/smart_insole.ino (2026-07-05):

/*
 * Smart Insole — dynamic plantar-pressure + IMU logger
 * ----------------------------------------------------
 * MCU  : ESP32-S3 (Arduino core v3.x)
 * Sense: 8x FSR402 via CD74HC4067 mux -> 1 ADC pin
 *        Adafruit BNO085 IMU (I2C)  ->  fused quaternion + accel
 * Store: microSD (SPI), CSV at ~100 Hz
 * Link : BLE Nordic-UART, notifies rows at ~20 Hz (SD keeps full rate)
 *
 * Button (GPIO14 -> GND): short press = start/stop recording,
 *                         long press  = cycle activity label.
 * LED (GPIO15): solid = recording, blink = idle.
 *
 * Libraries (Library Manager): "Adafruit BNO08x", "SD", core ESP32 BLE.
 * See ../../README.md for wiring + BOM.
 */

#include <Wire.h>
#include <SPI.h>
#include <SD.h>
#include <Adafruit_BNO08x.h>
#include <BLEDevice.h>
#include <BLEServer.h>
#include <BLEUtils.h>
#include <BLE2902.h>

// ---------- pins ----------
static const int MUX_SIG = 1;                 // ADC1_CH0
static const int MUX_S[4] = {2, 3, 4, 5};     // S0..S3
static const int I2C_SDA = 8, I2C_SCL = 9;
static const int SD_CS = 10, SD_MOSI = 11, SD_SCK = 12, SD_MISO = 13;
static const int PIN_BTN = 14, PIN_LED = 15;

// ---------- config ----------
static const int   NUM_FSR      = 8;
static const uint32_t SAMPLE_HZ = 100;
static const uint32_t SAMPLE_US = 1000000UL / SAMPLE_HZ;
static const int   BLE_DECIMATE = 5;          // BLE every 5th sample (~20 Hz)
const char* ACTIVITIES[] = {"stand","walk","fast_walk","stairs_up","stairs_down","pivot","single_leg"};
static const int NUM_ACT = sizeof(ACTIVITIES)/sizeof(ACTIVITIES[0]);

// ---------- state ----------
Adafruit_BNO08x bno;
sh2_SensorValue_t sv;
bool     recording = false;
int      activity  = 0;
File     logFile;
uint32_t t0_ms = 0, sampleCount = 0;
float    qw=1,qx=0,qy=0,qz=0, ax=0,ay=0,az=0;

// ---------- BLE ----------
#define NUS_SVC  "6E400001-B5A3-F393-E0A9-E50E24DCCA9E"
#define NUS_TX   "6E400003-B5A3-F393-E0A9-E50E24DCCA9E"
BLECharacteristic* txChar = nullptr;
bool bleConnected = false;
class SrvCB : public BLEServerCallbacks {
  void onConnect(BLEServer*)    { bleConnected = true; }
  void onDisconnect(BLEServer* s){ bleConnected = false; s->getAdvertising()->start(); }
};

void muxSelect(int ch){ for(int i=0;i<4;i++) digitalWrite(MUX_S[i],(ch>>i)&1); }
int  readFSR(int ch){ muxSelect(ch); delayMicroseconds(6); return analogRead(MUX_SIG); }

void setupBLE(){
  BLEDevice::init("SmartInsole");
  BLEServer* s = BLEDevice::createServer();
  s->setCallbacks(new SrvCB());
  BLEService* svc = s->createService(NUS_SVC);
  txChar = svc->createCharacteristic(NUS_TX, BLECharacteristic::PROPERTY_NOTIFY);
  txChar->addDescriptor(new BLE2902());
  svc->start();
  BLEAdvertising* adv = BLEDevice::getAdvertising();
  adv->addServiceUUID(NUS_SVC);
  adv->start();
}

void openNewLog(){
  char name[32];
  int idx = 0;
  do { snprintf(name,sizeof(name),"/log_%03d.csv", idx++); } while (SD.exists(name) && idx < 1000);
  logFile = SD.open(name, FILE_WRITE);
  if (logFile){
    logFile.println("t_ms,activity,fsr0,fsr1,fsr2,fsr3,fsr4,fsr5,fsr6,fsr7,qw,qx,qy,qz,ax,ay,az");
    Serial.printf("Recording -> %s (activity=%s)\n", name, ACTIVITIES[activity]);
  } else Serial.println("!! SD open failed");
  t0_ms = millis(); sampleCount = 0;
}

void handleButton(){
  static uint32_t downAt = 0; static bool wasDown = false;
  bool down = (digitalRead(PIN_BTN) == LOW);
  if (down && !wasDown){ downAt = millis(); wasDown = true; }
  if (!down && wasDown){
    uint32_t held = millis() - downAt; wasDown = false;
    if (held > 800){                                   // long: cycle activity
      activity = (activity + 1) % NUM_ACT;
      Serial.printf("Activity -> %s\n", ACTIVITIES[activity]);
    } else {                                           // short: start/stop
      recording = !recording;
      if (recording) openNewLog();
      else if (logFile){ logFile.flush(); logFile.close(); Serial.println("Stopped."); }
    }
  }
}

void readIMU(){
  if (bno.getSensorEvent(&sv)){
    switch (sv.sensorId){
      case SH2_ROTATION_VECTOR:
        qw=sv.un.rotationVector.real; qx=sv.un.rotationVector.i;
        qy=sv.un.rotationVector.j;    qz=sv.un.rotationVector.k; break;
      case SH2_LINEAR_ACCELERATION:
        ax=sv.un.linearAcceleration.x; ay=sv.un.linearAcceleration.y;
        az=sv.un.linearAcceleration.z; break;
    }
  }
}

void setup(){
  Serial.begin(115200);
  pinMode(PIN_BTN, INPUT_PULLUP); pinMode(PIN_LED, OUTPUT);
  for(int i=0;i<4;i++) pinMode(MUX_S[i], OUTPUT);
  analogReadResolution(12); analogSetAttenuation(ADC_11db);   // 0..~3.3V

  Wire.begin(I2C_SDA, I2C_SCL);
  if (!bno.begin_I2C()) Serial.println("!! BNO085 not found");
  else { bno.enableReport(SH2_ROTATION_VECTOR, 5000); bno.enableReport(SH2_LINEAR_ACCELERATION, 5000); }

  SPI.begin(SD_SCK, SD_MISO, SD_MOSI, SD_CS);
  if (!SD.begin(SD_CS)) Serial.println("!! SD init failed (BLE stream still works)");

  setupBLE();
  Serial.println("Ready. Short press = start/stop, long press = change activity.");
}

void loop(){
  static uint32_t nextUs = micros();
  handleButton();
  readIMU();

  if ((int32_t)(micros() - nextUs) >= 0){
    nextUs += SAMPLE_US;
    if (recording){
      uint32_t t = millis() - t0_ms;
      int f[NUM_FSR]; for (int i=0;i<NUM_FSR;i++) f[i]=readFSR(i);

      char row[192];
      int n = snprintf(row,sizeof(row),
        "%lu,%s,%d,%d,%d,%d,%d,%d,%d,%d,%.4f,%.4f,%.4f,%.4f,%.3f,%.3f,%.3f",
        (unsigned long)t, ACTIVITIES[activity],
        f[0],f[1],f[2],f[3],f[4],f[5],f[6],f[7], qw,qx,qy,qz, ax,ay,az);

      if (logFile) logFile.println(row);
      if (bleConnected && txChar && (sampleCount % BLE_DECIMATE == 0)){
        row[n++]='\n'; row[n]=0; txChar->setValue((uint8_t*)row, n); txChar->notify();
      }
      if ((sampleCount & 0x7F)==0 && logFile) logFile.flush();   // periodic flush
      sampleCount++;
      digitalWrite(PIN_LED, HIGH);
    } else {
      digitalWrite(PIN_LED, (millis()/500)&1);                   // idle blink
    }
  }
}

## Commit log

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2026-07-05 docs: fix CHEEQ tagging after actually reading dizzyvinci/cheeq
    Cheeq is a full startup with its own authoritative BOM (02_product/build-protocol-V1.md).
    Replaced my from-memory (partly wrong) Cheeq parts list with a correct concise pointer:
    - backing is silicone (Ecoflex 00-50 / Dragon Skin 10), NOT PLA
    - the real cost driver is the vacuum degasser, which I'd omitted
    - no 3D printer needed for Cheeq; source of truth = the cheeq repo
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2026-07-05 path2: all-day tracking build — barefoot+shoe firmware + print-ready pod & sole + build guide
    - firmware/all_day_logger: continuous 50Hz SD logging, batched writes, BLE off,
    shoe<->barefoot mode toggle, battery logging, file rotation (~8-14h on 1000-1500mAh)
    - hardware/ankle_pod.scad: parametric ESP32+LiPo+SD pod (electronics live OFF the foot)
    - hardware/barefoot_sole.scad: thin TPU footbed with 8 FSR pockets + strap slots (barefoot rig)
    - docs/path2_tracking_build.md: barefoot-vs-shoe, battery table, 3 prints, assembly, daily workflow
    [ankle_pod.scad, barefoot_sole.scad]
2026-07-05 analysis: real-pressure (kPa) calibration pipeline
    - analysis/calib.py: ADC -> divider resistance -> conductance -> Force (F=a*G^b) -> kPa
    - analysis/calibrate.py: fit per-sensor power law from known-weight points -> calibration.json
    - analysis/cal_points_template.csv + firmware/fsr_calibrate: collect the points
    - interpret.py: --calibration outputs real kPa (verified end-to-end on shoe+barefoot logs)
    - docs/calibration.md: 20-min procedure + the model + honest accuracy notes
    Verified: template fit R2=0.99; full run produces per-condition kPa findings +
    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
    [cal_points_template.csv]
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2026-07-05 expand: balance module (posturography) + prototype/pitch pack + print-ready model docs + graphics
    - analysis/balance.py: sway ellipse area/velocity, ML/AP, trunk sway, Romberg, fall-risk flags
    (verified: eyes-closed sway 2970 vs eyes-open 1308 mm2, Romberg>2) + docs/balance.md
    - hardware/README.md: STL export (OpenSCAD) + print settings per part
    - docs/prototype_status.md: what's ordered vs printed, lifespans, pitch-ready capabilities
    - docs/parts_ordered_vs_printed.svg + docs/software_metrics.svg: annotated graphics
    - README: embed new graphics + point to balance module & prototype status
    Balance = an extrapolation of the same hardware to stability/fall-risk, not just foot pressure.
    Co-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
2026-07-05 hardware: ship pre-rendered STLs + preview PNGs (ready to slice)
    Rendered ankle_pod.stl / barefoot_sole.stl from the .scad models via
    OpenSCAD so they can be sliced in Bambu Studio directly, no OpenSCAD
    install required. Add preview PNGs, un-ignore hardware/*.stl, and note
    in hardware/README that STLs are committed.
    [ankle_pod.stl, barefoot_sole.stl]
2026-07-05 worked example: synthetic day -> kPa -> auto-designed insole + balance
    Add a self-contained, self-demonstrating demo so the repo shows real output
    with no hardware:
    - analysis/make_sample_data.py: physically-consistent synthetic day (walking
    shoe/barefoot with a medial-heel hot spot; quiet-standing eyes-open/closed
    with a vision-reliant balance pattern). Same ground-truth (a,b) used for the
    calibration points, so calibrate.py recovers it (R2=1.00).
    - analyze_pressure.py: accept --calibration (power-law kPa via calib.py) so it
    agrees with interpret.py; fix the blank peak-pressure map (Gaussian-splat
    field instead of NaN-sparse grid); label units (kPa/N/rel).
    - hardware/build_insole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
    [cal_points.csv, relief_insole.scad, relief_insole.stl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]
2026-07-05 graphics: flesh out annotated diagrams (code-generated, real numbers)
    Add docs/make_graphics.py so diagrams are reproducible with exact geometry,
    and regenerate a richer set carrying the worked-example numbers:
    - physical_setup.svg: how it's worn — ankle pod (contents), thin ribbon, the
    8-zone sensor sole, barefoot-vs-shoe sole swap.
    - pipeline.svg: measure->design->print->re-measure loop with real values
    (calibrate R2=1.0 -> heel_med 645 kPa -> build_insole.py -> H2D -> iterate).
    - software_metrics.svg: two modules with a mini peak-pressure heatmap + sway
    ellipses and worked-sample directives.
    - day_in_the_life.svg (new): daily wear timeline + battery drain + per-piece
    lifespan c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
2026-07-05 add PITCH.md — one-page pitch (problem → $100 wearable → two modules → numbers)
2026-07-05 insole: fit to your foot — measurements or a scan of your orthotic
    build_insole.py gains two geometry-fit modes on top of the data-driven relief:
    - Measurements: --length/--forefoot-width/--heel-width/--arch-height scale the
    parametric footbed (adds a medial arch dome); --side left mirrors it.
    - Scan: --scan orthotic.stl imports your real geometry (binary+ASCII STL bbox
    parser), maps the hot-spot zone onto the scan, finds the LOCAL top surface
    there, and carves the relief pocket into your actual contour.
    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
    [relief_insole.scad, relief_insole.stl]
2026-07-05 balance: protocol-aware analysis across stance positions + arch auto-suggest
    New analysis/balance_positions.py — the full clinical battery on the same rig:
    - mCTSIB (firm/foam x eyes open/closed) -> sensory-reliance ratios
    (vision / somatosensory / vestibular) + composite sway
    - Romberg, single-leg L-vs-R asymmetry, tandem, and Limits-of-Stability
    (directional COP reach + convex-hull LOS area)
    - per-position load distribution (heel/forefoot, medial/lateral) from the FSRs
    Recognises label aliases; reuses balance.py's COP/sway core.
    make_sample_data.py emits a seeded positions battery (sample_balance_positions.csv)
    appended AFTER existing data so the committed 770/211/Romberg-3.6 number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
    [relief_insole.stl, sample_balance_positions.csv]
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2026-07-05 beam_balance: specialized athlete balance (gymnasts) — landing stick + ML control
    analysis/beam_balance.py — elite balance instead of clinical:
    - static holds: mediolateral-focused sway + grade (beam = 10cm, ML = falling off)
    - landing 'stick' score: detect impact, then settle time / post-landing sway /
    wobble count / step detection -> judge-style 0-10 (wobble ~0.1, step ~0.5).
    Edge-padded COP smoothing so sensor noise isn't read as wobble.
    - releve load (forefoot vs heel), and an athlete Romberg (low eyes-closed = elite)
    Demo verified: clean landing 10.0 (STUCK), wobble+step 9.2, releve hold ML 0.42mm.
    Frames the strategy the user called out: own the foot-pressure/COP layer video
    c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
2026-07-05 landing_lab: discipline-aware landings (gymnastics stick / skating edge / dance roll)
    analysis/landing_lab.py — same insole, three rubrics (all land forefoot-first,
    then diverge):
    - gymnastics: settle-to-stillness 'stick' (wobbles/step deduct)
    - figure_skating: single-foot edge check-out — edge (ML) control + forward
    flow-out + soft plié; step-out/stumble/slam deduct
    - dance: soft rolled landing — impact softness + toe->ball->heel roll (heel-lag)
    + plié; heavy/flat deduct
    Shared landing primitives (impact, loading rate, roll-lag, edge, flow) reused
    from beam_balance/balance. Demo verified: gym 9.8 STUCK, skating 9.7 edge, dance
    9.9 soft. Tightened the demo COP synthesis so glide-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
2026-07-05 engine v0.4: condition-aware — plantar fasciitis / toe-walking / equinus (cited)
    Deep-researched adaptive/altered gait baselines so the engine doesn't false-flag them:
    - refs/plantar_norms.json: condition profiles with real numbers + sources —
    plantar_fasciitis (altered medial-heel + forefoot overstrain, PMC5773441),
    toe_walking (ITW forefoot 61.7/midfoot 15.3/hindfoot 22.8% vs normal ~39/-/30,
    PubMed 31946390; adaptive=true), equinus (forefoot peak 677.8 vs 565.6 kPa,
    PMC9338503). condition_notes + ASD-gait source (PMC9993582).
    - analysis/zone_load.py --condition: for adaptive patterns, annotates low-heel
    under-use as 'expected — adaptive baseline, not a flag'; surfaces the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
2026-07-05 lab scope: equipment gap analysis — 3D-print/DIY vs the papers' gear
    Deep-researched the instruments behind the cited studies and mapped the DIY path:
    - refs of pro kit: pedar (capacitive, RMSE 2.6 kPa, $10-30k), emed/MatScan platforms
    (1.4-2 sensors/cm2), AMTI/Kistler force plates ($5-30k), tri-axial shear, Vicon.
    Capacitive beats resistive (FSR drifts: hysteresis/creep) -> calibration tax.
    - What we DIY: FSR insole (have, r~0.87); Velostat copper-matrix pressure MAT (3D-print
    frame, ~$40, Hackaday 7000-cell precedent maps heel/arch/forefoot); load-cell +
    HX711 force plate on a printed top (~$80, ICC>0.94 vs plate); video->force (free);
    calibrate.py. ~$150-250 of parts on top of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
2026-07-05 build guides: printable DIY force plate + Velostat pressure mat + firmware
    Turn the lab-scope plan into real, buildable files:
    - hardware/force_plate.scad (parametric load-cell corner feet + top bosses + plate) ->
    STL; firmware/force_plate (4x HX711 -> per-corner force -> vertical GRF in N/xBW +
    center of pressure). Unlocks the xBW landing/jump numbers the insole can't.
    - hardware/pressure_mat.scad (rigid frame + electrode-alignment comb + cable slot) ->
    STL; firmware/pressure_mat (Velostat ROWxCOL matrix scan via GPIO rows + CD74HC4067
    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
    [force_plate.scad, force_plate.stl, pressure_mat.scad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]
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2026-07-05 maker hacks: recover the accuracy cheap sensors lose
    Cited toolbox (docs/maker_hacks.md) + baked-in implementations:
    - force_plate.ino: median-then-average HX711 filter + SPS-for-the-job
    - pressure_mat.ino: anti-ghost scan (idle rows sunk LOW + settle-throwaway read)
    - analysis/mat_heatmap.py: bicubic interpolation of the coarse matrix -> clean map
    - hardware/fsr_puck.scad/stl: printable FSR force-concentrator puck
    - docs/maker_hacks.svg gallery graphic; README/build_lab/hardware cross-links
    [fsr_puck.scad, fsr_puck.stl]
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2026-07-05 nerve/fascia on REAL numbers: day_summary bridge + firmware phase tag + insole fold-in
    - analysis/day_summary.py: raw session logs -> per-zone peak/PTI-per-cycle/cycles-per-day,
    auto-splitting gait vs at-rest bounce (calibrated kPa). Emits day.json.
    - nerve_fascia.py: consumes rich day schema (gait PTI x gait cycles + bounce PTI x bounce
    cycles; measured PTI encodes under-loading, no fudge) + one-command --logs path.
    - interpret.py: DB-driven 'structure watch' -> relief target follows the nerve/fascia read.
    - firmware/all_day_logger: column (short-press cycles walk/stand/bounce/other) so a
    day segments for the CPTS model.
    - make_sample_data: seated_bounce sample (isolated rng); full s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
    [sample_seated_bounce.csv]
2026-07-05 insole acts on structure_target + CPTS trend tracking
    build_insole.py: metatarsal pad proximal to the met heads when Morton is the target;
    auto-enable arch support for a plantar-fascia/tibial target. The print follows the
    nerve/fascia read, not just the peak-pressure zone. Sample insole now gains arch support.
    analysis/trend.py: record day.json snapshots + chart CPTS per structure over days/weeks
    (reuses nerve_fascia.analyze). Demo shows forefoot structures falling after a week-3
    intervention while heel-only Baxter holds flat. nerve_fascia.py: extracted analyze().
    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
    [relief_insole.scad, relief_insole.stl]
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2026-07-18 Add ankle-pod enclosure + insole FSR layout, models and build plan
    3D-printable ankle pod (ESP32-C6 Feather + LiPo 2500mAh + MPU-6050),
    6-zone FSR insole carrier (matches the Feather's 6 ADC pins, no mux),
    sensor-layout doc, and a stepwise Bambu H2D build plan. STLs rendered
    from the parametric OpenSCAD sources and verified to compile.
    [ankle_pod_enclosure.scad, ankle_pod_enclosure.stl, insole_fsr_layout.scad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]
2026-07-19 Re-spec ankle pod for a flat-pouch LiPo (form factor is a constraint)
    The 2500mAh cell (50x34x10) drove the case width and made the pod too bulky
    for a body-worn part. Variants of this pod ride the shin, foot, in-shoe and
    on an AFO, so the cell must be a flat pouch -- a cylindrical 18650 is a rigid
    tube that cannot sit under the board or against a limb (keep 18650s for the
    stationary bed-mat / force-plate builds only).
    Default is now a 1200mAh flat pouch (35x20x6). At 20mm the cell is narrower
    than the Feather, so the board governs case width: the shell loses ~12mm of
    width and standoff_h drops 11mm -> 7mm. Documents 500/1200/2000/2500mAh
    options with runtimes; runtime is not binding since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
    [ankle_pod_enclosure.scad, ankle_pod_enclosure.stl]
2026-07-20 Add pin-by-pin wiring guide; resize IMU bay for BNO085
    WIRING.md fills the gap BUILD_PLAN.md left ('solder to perfboard' with no
    connections): FSR divider theory, zone->ADC pin table (heel_med..hallux ->
    A0..A5), perfboard layout matching the enclosure's exit slot, solder order,
    and a multimeter pre-power checklist with expected divider resistances.
    Calls out up front that the whole I2C sensor chain is STEMMA-QT plug-in --
    the FSR dividers are the only solder in the build. 10k fixed resistor
    matches calibrate.py's existing r_fixed default.
    Also fixes a real dimensional conflict the wiring pass surfaced: the IMU bay
    was cut 18x13 for the MPU-6050, but the incoming BNO085 is ~25.5x17.8 and
    wo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
    [ankle_pod_enclosure.scad, ankle_pod_enclosure.stl]
2026-07-20 Add I2C bring-up scanner; size IMU bay for the BNO085
    i2c_scanner.ino is the first sketch to run on the Feather -- it pings the
    whole bus and annotates the addresses this project actually uses, so the
    output explains itself. Separates a dead sensor from an unseated STEMMA QT
    cable, which is the real failure mode ~90% of the time.
    Enclosure fix: the IMU bay was cut 18x13mm for the MPU-6050, but the BNO085
    upgrade is ~25.5x17.8mm and would NOT have fit. Bay is now sized for the
    larger board; retention is a lip + zip-tie rather than an interference fit,
    so the smaller MPU-6050 still sits fine. Also documents that the BNO085
    answers on 0x4A, not the MPU-6050's 0x68 -- firmware hard-coding 0x68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
    [i2c_scanner.ino]
2026-07-20 docs: connection diagram for the Feather <-> MPU-6050 bring-up
    Renders a labelled top view of the first sensor hookup, so the no-soldering
    path is something you can look at rather than parse from prose.
    Carries the two facts that actually cost time. The MPU-6050's two STEMMA ports
    are wired in parallel, so either one works and the spare is for chaining a
    third board. And the Feather's STEMMA port stays UNPOWERED until firmware
    drives IO20 HIGH -- a correctly plugged sensor still reports nothing until it
    does, which looks exactly like a dead sensor.
    Marked in the header as a connection schematic, NOT a scale drawing: board
    outlines are close to real but connector positions along an edge are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
    [stemma_wiring_diagram.scad]
2026-07-20 i2c_scanner: actually power the STEMMA QT port before scanning
    docs/WIRING.md line 252 already recorded that IO20 must be driven HIGH for the
    STEMMA QT connector to power up, and called it a firmware step -- but the
    firmware never did it. The sketch went straight to Wire.begin() on a port that
    is unpowered at boot, so it would have reported "No I2C devices found" on a rig
    wired perfectly, and sent the first bring-up session debugging a cable that was
    fine.
    Drives IO20 HIGH before Wire.begin(), with a 50ms wait so the sensor can finish
    its own power-on reset.
    Also explains what the step means in beginner terms, because "drive IO20 HIGH"
    is not self-evident: IO20 is a GPIO pin, HIGH means 3.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
    [i2c_scanner.ino]
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2026-08-01 Build-ready sweep + 2026-08-01 parts reconcile
    Fix gate-fails (foot_blade_mount, chest_yoke, outrigger, fab pcb_fixture,
    mag halbach jig), export missing STLs (head-neck-support wings/pads,
    flywheel_rim_carrier), scope DAVIT (STLs/.3mf/ASSEMBLY), fix glasses-HUD
    dock islands, mark 2026-08-01 delivered parts owned across BOMs, update inventory.
    [ankle_pod.3mf, ankle_pod_enclosure.3mf, barefoot_sole.3mf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]
2026-08-07 firmware: commit the force_plate rewrite + inline HX711 driver (was untracked)
    hx711_lite.h and force_plate/README.md were UNTRACKED, and force_plate.ino /
    fsr_calibrate.ino were uncommitted. This is the firmware for the only subsystem in
    the tree whose hardware is already printed and on the desk (job 1148490506).
    hx711_lite.h exists so this sketch has ZERO external dependencies. It is not merely a
    workaround for a missing library: the stock HX711 library's wait_ready() blocks
    forever on an absent or miswired amp, and on a rig operated by someone with reduced
    protective sensation a silent hang is indistinguishable from "no load applied". Every
    read here is timeout-guarded and reports #FAULT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
    [force_plate.ino, fsr_calibrate.ino, hx711_lite.h]
2026-08-07 Close the pressure chain: nothing could read force_plate's output
    force_plate.ino v2.0.0 emits a self-describing log -- a '#' header block
    carrying the calibration that produced the numbers, the five condition fields,
    the plate geometry, the safety ceilings, then '#COLS', then CSV. Every script
    in analysis/ was written against the older smart_insole format and skips '#'
    lines, so all of that was silently discarded on the way in. A run landed
    downstream as bare numbers with no coordinates, which is exactly the failure
    this repo's own rule names: a reading without its condition is not usable.
    ingest_force_plate.py parses the header into a session manifest, runs QC gates
    that can REFUSE, recon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
